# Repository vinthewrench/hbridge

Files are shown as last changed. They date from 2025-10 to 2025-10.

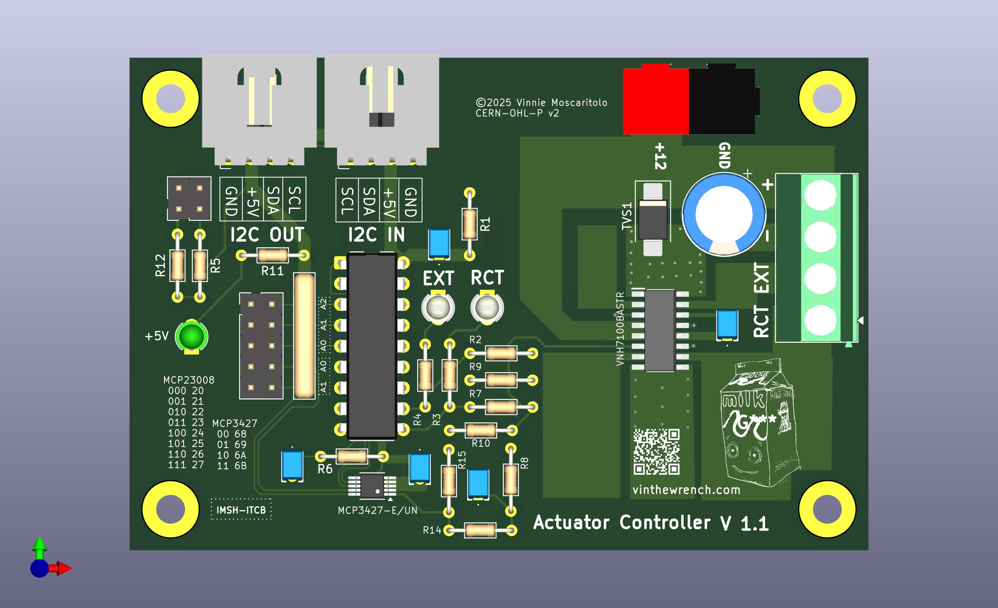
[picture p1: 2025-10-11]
Hbridge F.jpg

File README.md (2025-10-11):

# Actuator Controller – I²C Smart H-Bridge Board

This board is a smart linear actuator controller that uses a VNH7100BAS H-bridge with current sensing and I²C control. It is designed for 12 V actuators, supports stall/jam detection, and is chainable over I²C so you can run multiple actuators from one controller without burning GPIO pins.

This board is part of my distributed control system and is compatible with my nodeLync I²C wiring standard.

## Features
- Drives 12 V linear actuators (extend/retract)
- Solid-state H-bridge (no relays to weld shut)
- Current sensing for stall/jam detection
- I²C control using MCP23008 GPIO expander
- Optional MCP3427 ADC for current telemetry
- Motor power terminal or Anderson Powerpole input
- Status LEDs for power and activity
- Designed for Raspberry Pi or microcontroller systems
- Open hardware – modify it, build it, use it

## I²C Addresses
	| Device        | Base Address | Configurable         |
	|---------------|--------------|----------------------|
	| MCP23008 GPIO | 0x20–0x27    | Yes (A0–A2 jumpers)  |
	| MCP3427 ADC   | 0x68–0x6B    | Yes (ADDR pin)       |

## Current Measurement
The VNH7100BAS provides a current sense output. In 12-bit mode:
Useful for overload protection and detecting mechanical faults.

## Documentation
Full design writeup:
https://www.vinthewrench.com/p/the-humble-actuator

Demo video:
https://youtu.be/HOyxq8rQfaQ

## Status
✅ Prototype tested  
✅ Verified on Raspberry Pi  
✅ Load tested with Progressive Automations PA-10 and PA-14 actuators  
✅ Ready for fabrication / community mods

## License
This is Open Hardware under the CERN-OHL-P v2 license.

You can build it, modify it, use it commercially, and keep modifications private if you want. Just do not remove the original credit.

SPDX-License-Identifier: CERN-OHL-P-2.0  
© 2025 Vinnie Moscaritolo

## Contributions
Issues and pull requests are welcome. If you build one, I would like to see it.

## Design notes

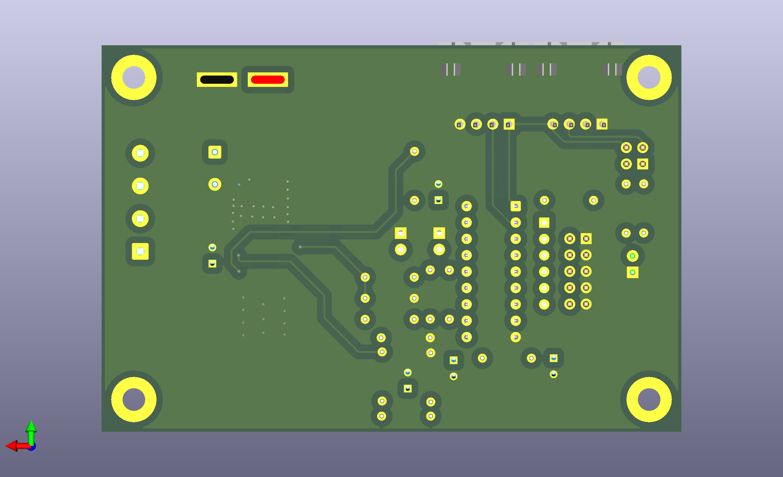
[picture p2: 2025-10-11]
Hbridge B.png

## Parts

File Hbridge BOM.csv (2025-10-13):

H-Bridge Bill of materials
Quantity | Designator | Designation | Mfg Part | Supplier Part | Cost | Ext | Footprint
5 | C21,C5,C6,C2,C1 | .1uf | RCER71H104K0DBH03A | 81-RCER71H104K0DBH3A | $0.18 | $0.92 | Multilayer Ceramic Capacitors MLCC - Leaded .1UF 50V 10% 2.5MM
1 | C3 | 1000uf | EEU-FR1E102 | 667-EEU-FR1E102 | $0.45 | $0.45 | Aluminum Electrolytic Capacitors - Radial Leaded 25VDC 1000uF 10x20mm
2 | J1, J2 | nodeLync socket | 538-70551-0003 | 70551-0003 | $1.19 | $2.38 | Molex Headers & Wire Housings SL 4 CKT W-T-B SHROU
 | J3 | Conn_02x05_Odd_Even |  |  |  | 0
1 | J4 | Screw_Terminal_01x4 | 1715747 | 651-1715747 | $2.21 | $2.21 | Fixed Terminal Blocks 4P 5.08mm 90DEG
1 | J5 | 45A-VERT-PAIR | SSQ-108-04-L-D | 200-SSQ10804LD | $3.28 | $3.28 | Heavy Duty Power Connectors PP PCB STRAIGHT
1 | J6 | Conn_02x02_Odd_Even |  |  |  | 0
3 | LED3,LED2,LED1 | LED 3mm Green/Red | 151033GS03000 | 710-151033GS03000 | $0.25 | $0.75 | Single Color LEDs WL-TMRW THT Mono Waterclr Rnd 3mm Grn
4 | R4,R12,R5,R3 | 4.7K | MBA02040C4701FRP00 | 594-5063JD4K700FT | $0.11 | $0.44 | Metal Film Resistors - Through Hole .4watt 4.7Kohms 1% 1/8watt
1 | R11 | 150 | MBA02040C1500FRP00 | 594-5063JD150R0FT | $0.10 | $0.10 | Metal Film Resistors - Through Hole .4watt 150ohms 1% 1/8watt
6 | R6,R14,R15,R9,R10,R1 | 10K | MBA02040C1002FRP00 | 594-5063JD10K1%TR | $0.10 | $0.60 | Metal Film Resistors - Through Hole .4watt 10Kohms 1% 1/8watt
3 | R7,R8,R2 | 1K | MBA02040C1001FRP00 | 594-5063JD1K000FT | $0.10 | $0.30 | Metal Film Resistors - Through Hole .4watt 1Kohms 1% 1/8watt
1 | RN1 | 10K | 4606M-101-103LF | 652-4606M-1LF-10K | 0.57 | 0.57 | Resistor Networks & Arrays 6pins 10Kohms Bussed
8 | TSV1 | P6SMB18A | P6SMB18A | 652-P6SMB18A | $0.22 | $1.76 | ESD Protection Diodes / TVS Diodes 18V 600W UniDir
1 | U1 | MCP23008-E/P | MCP23008-E/P | 579-MCP23008-E/P | $1.54 | $1.54 | Interface - I/O Expanders In/Out I2C int DIP
1 | U2 | VNH7100BASTR | VNH7100BASTR | 511-VNH7100BASTR | $3.38 | $3.38 | Motor / Motion / Ignition Controllers & Drivers Low Side Driver 1.5A /3A A 595-DRV103H/2K5
1 | U3 | MCP3427-E/UN |  | 579-MCP3427E/UN | $3.68 | $3.68
1 | PCB | PCBoard 60*90 |  |  | $0.65 | $0.65 | PCBway board
 |  |  |  |  | Total Cost | $23.01

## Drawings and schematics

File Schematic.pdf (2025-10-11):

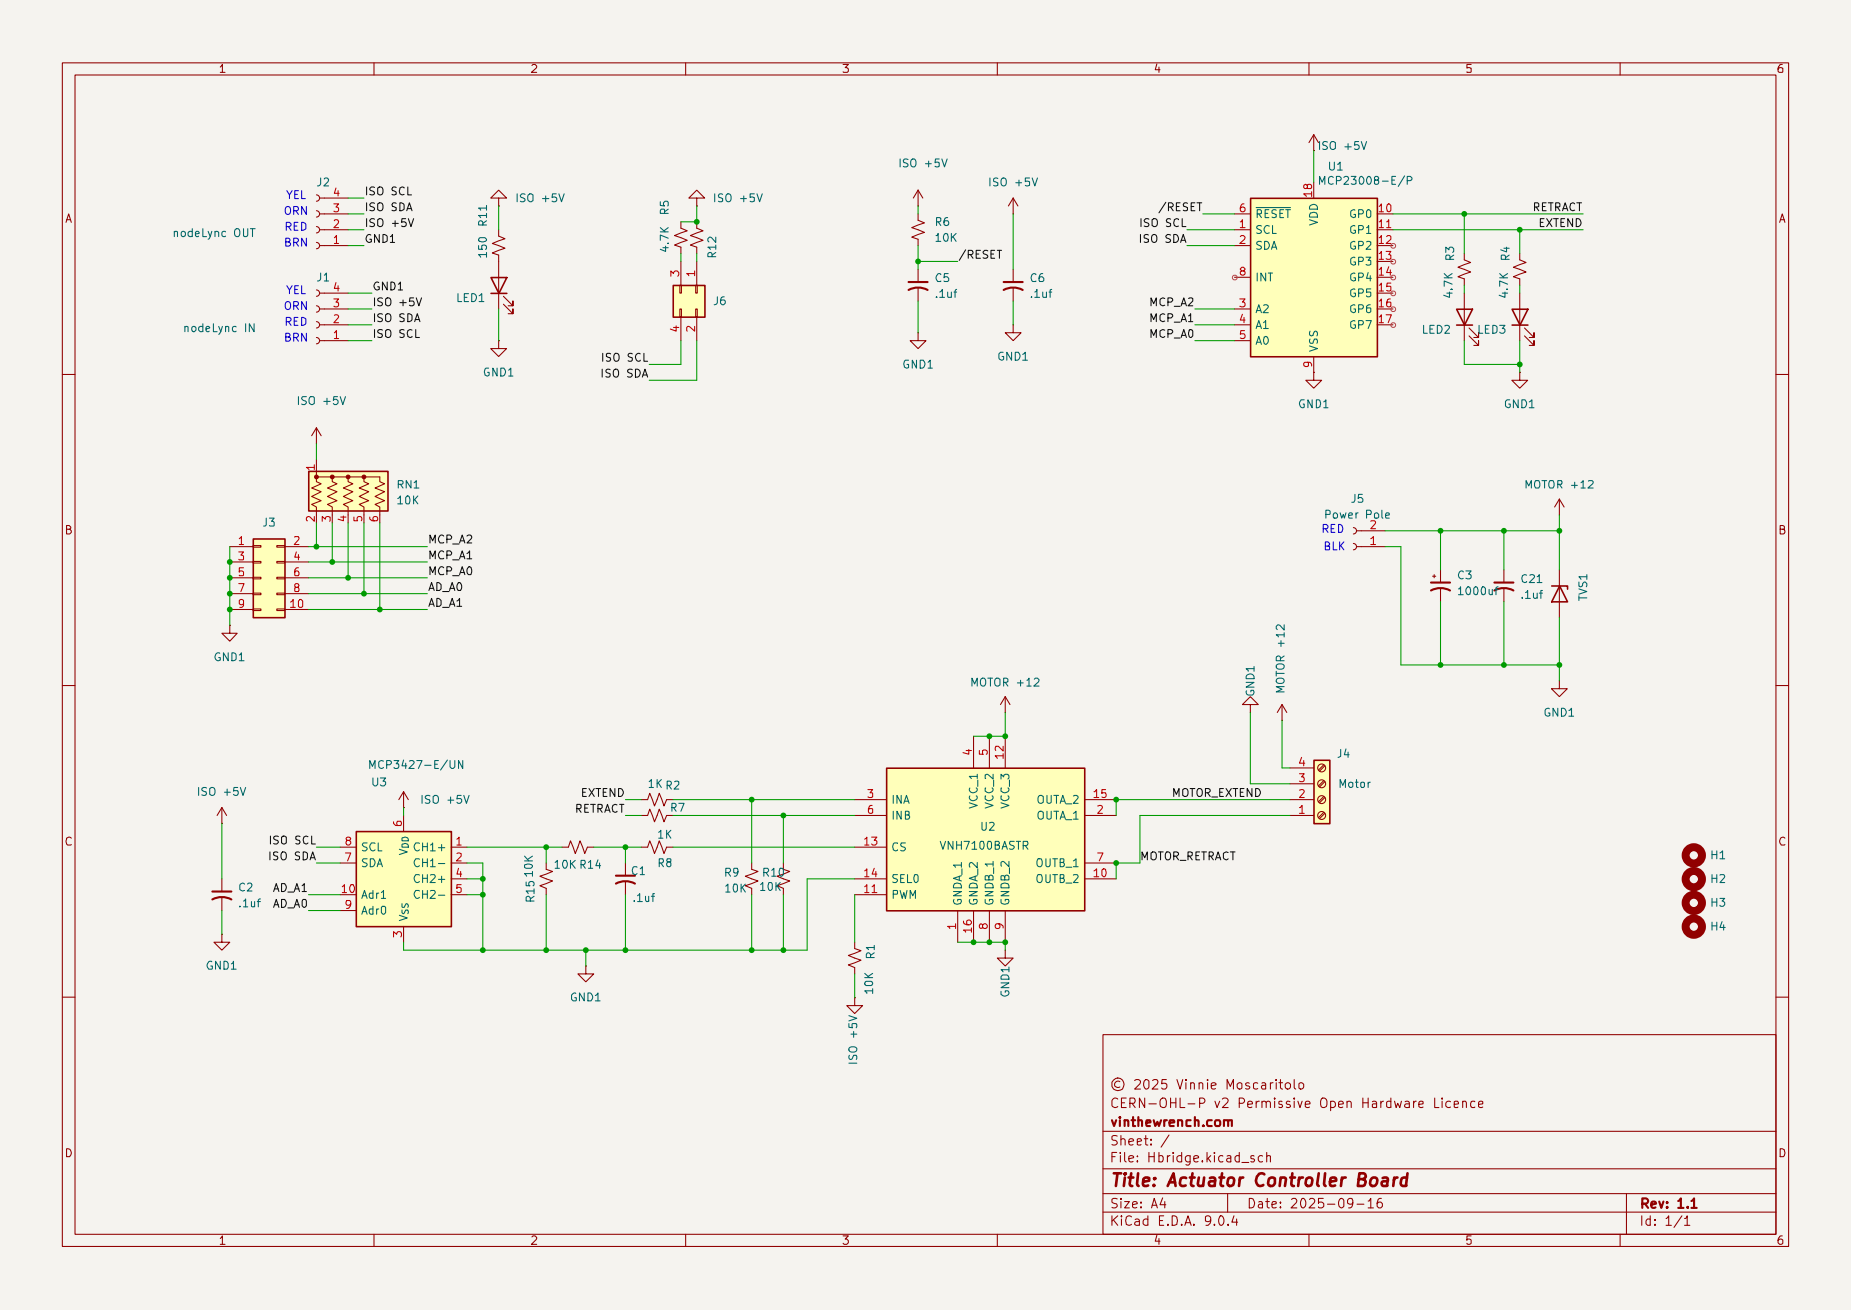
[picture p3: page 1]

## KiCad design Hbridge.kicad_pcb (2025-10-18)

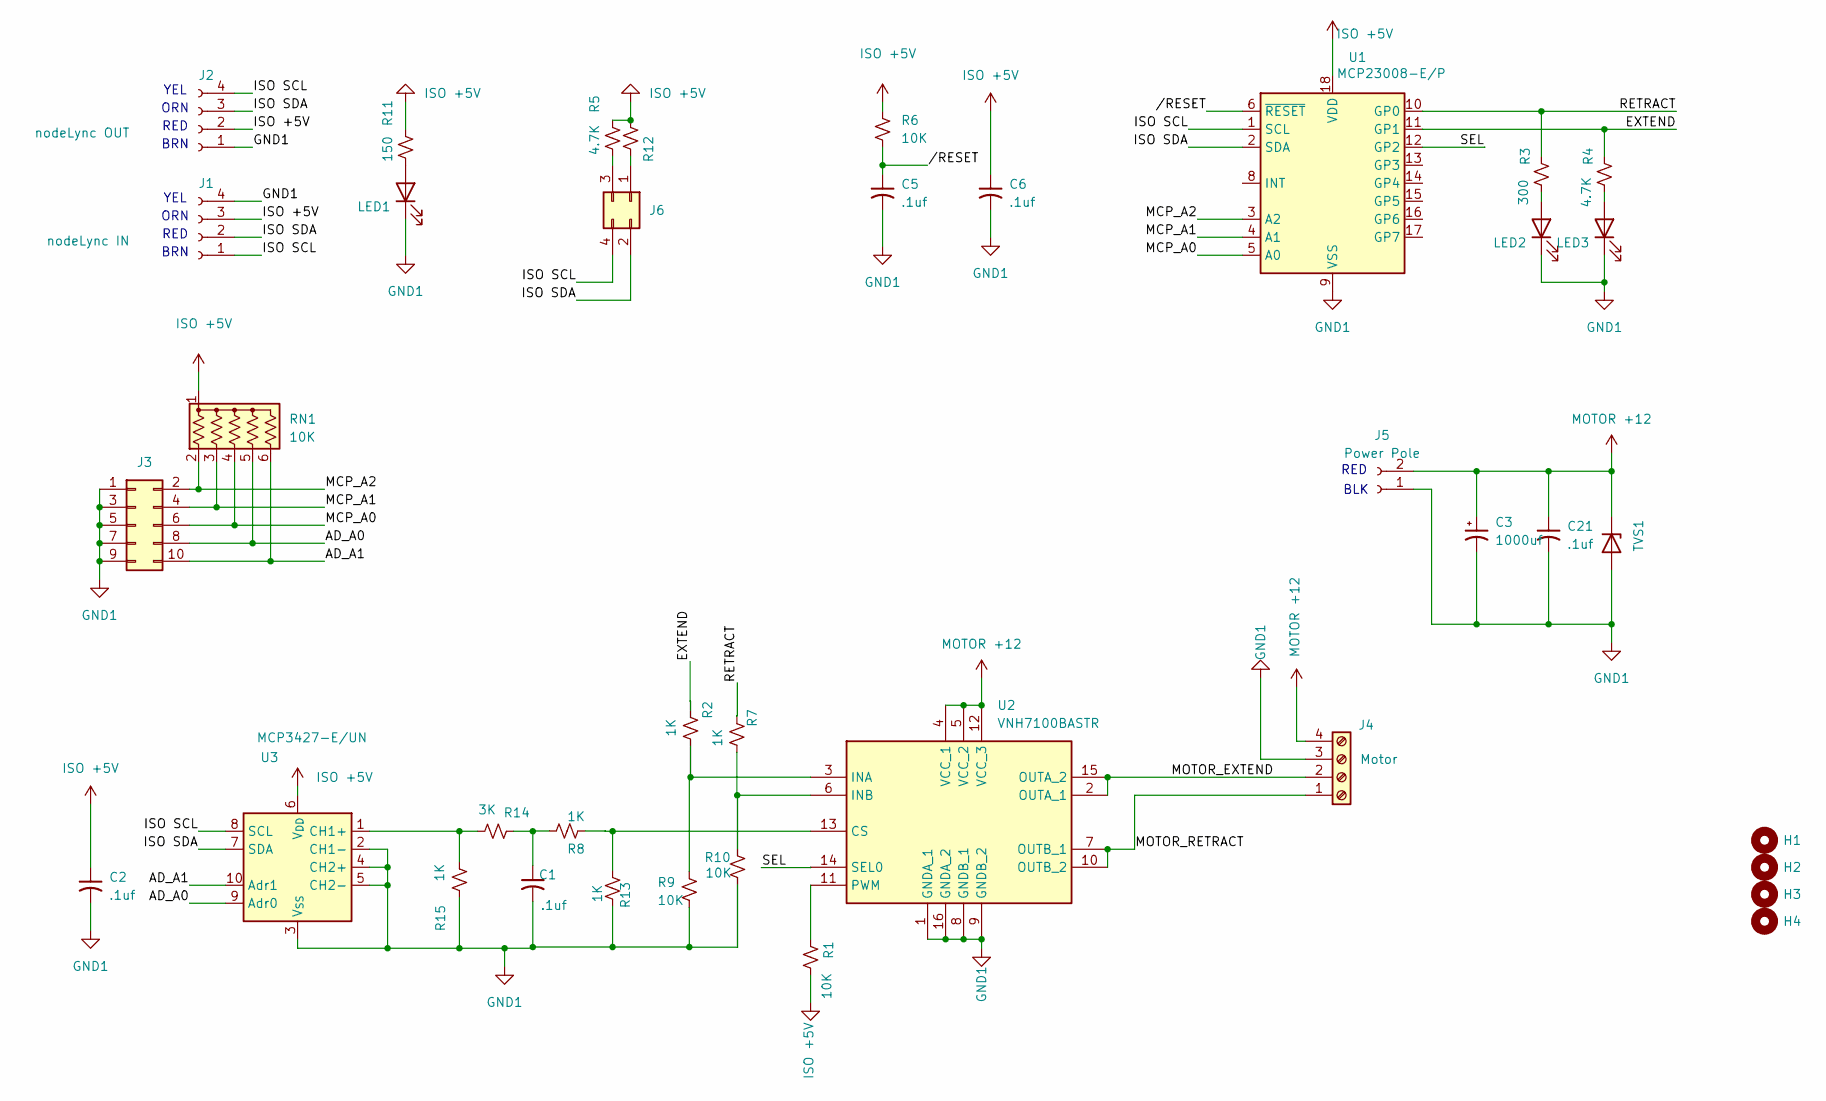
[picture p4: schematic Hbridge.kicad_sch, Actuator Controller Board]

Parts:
C1, C2, C5, C6, C21: .1uf; RCER71H104K0DBH03A
C3: 1000uf; CP_Radial_D10.0mm_P5.00mm
H1, H2, H3, H4: MountingHole
J1: nodeLync IN; PinHeader_1x04_P2.54mm_Horizontal
J2: nodeLync OUT; PinHeader_1x04_P2.54mm_Horizontal
J3: Conn_02x05_Odd_Even; PinHeader_2x05_P2.54mm_Vertical
J4: Motor; TerminalBlock_Phoenix_MKDS-1,5-4-5.08_1x04_P5.08mm_Horizont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
J5: Power Pole; 45A-VERT-PAIR
J6: Conn_02x02_Odd_Even; PinHeader_2x02_P2.54mm_Vertical
LED1, LED2, LED3: 151033GS03000; LED_D3.0mm
R1, R6, R9, R10: 10K; R_Axial_DIN0204_L3.6mm_D1.6mm_P7.62mm_Horizontal
R2, R7, R8, R13, R15: 1K; R_Axial_DIN0204_L3.6mm_D1.6mm_P7.62mm_Horizontal
R3: 300; R_Axial_DIN0204_L3.6mm_D1.6mm_P7.62mm_Horizontal
R4, R5, R12: 4.7K; R_Axial_DIN0204_L3.6mm_D1.6mm_P7.62mm_Horizontal
R11: 150; R_Axial_DIN0204_L3.6mm_D1.6mm_P7.62mm_Horizontal
R14: 3K; R_Axial_DIN0204_L3.6mm_D1.6mm_P7.62mm_Horizontal
RN1: 10K; R_Array_SIP6
TVS1: P6SMB18A; D_SMB_Handsoldering
U1: MCP23008-E/P; DIP-18_W7.62mm
U2: VNH7100BASTR; SOIC127P600X175-16N; Manufacturer_Part_Number VNH7100BASTR; Mouser Part Number 511-VNH7100BASTR
U3: MCP3427-E/UN; MSOP-10_3x3mm_P0.5mm

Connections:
/AD_A0: J3.8, RN1.5 (R4), U3.9 (Adr0)
/AD_A1: J3.10, RN1.6 (R5), U3.10 (Adr1)
/EXTEND: R2.2, R4.2, U1.11 (GP1)
/ISO SCL: J1.1, J2.4, J6.4, U1.1 (SCL), U3.8 (SCL)
/ISO SDA: J1.2, J2.3, J6.2, U1.2 (SDA), U3.7 (SDA)
/MCP_A0: J3.6, RN1.4 (R3), U1.5 (A0)
/MCP_A1: J3.4, RN1.3 (R2), U1.4 (A1)
/MCP_A2: J3.2, RN1.2 (R1), U1.3 (A2)
/MOTOR_EXTEND: J4.2, U2.2 (OUTA_1), U2.15 (OUTA_2)
/MOTOR_RETRACT: J4.1, U2.7 (OUTB_1), U2.10 (OUTB_2)
/RETRACT: R3.2, R7.2, U1.10 (GP0)
/SEL: U1.12 (GP2), U2.14 (SEL0)
//RESET: C5.1, R6.2, U1.6 (~RESET)
GND1: C1.2, C2.2, C3.2, C5.2, C6.2, C21.2, J1.4, J2.1, J3.1, J3.3, J3.5, J3.7, J3.9, J4.3, J5.1, LED1.1 (K), LED2.1 (K), LED3.1 (K), R9.2, R10.2, R13.1, R15.2, TVS1.2 (A), U1.9 (VSS), U2.1 (GNDA_1), U2.8 (GNDB_1), U2.9 (GNDB_2), U2.16 (GNDA_2), U3.2 (CH1-), U3.3 (V_{SS}), U3.4 (CH2+), U3.5 (CH2-)
ISO +5V: C2.1, C6.1, J1.3, J2.2, R1.2, R5.2, R6.1, R11.2, R12.2, RN1.1 (common), U1.18 (VDD), U3.6 (V_{DD})
MOTOR +12: C3.1, C21.1, J4.4, J5.2, TVS1.1 (K), U2.4 (VCC_1), U2.5 (VCC_2), U2.12 (VCC_3)
unnamed: C1.1, R8.1, R14.2
unnamed: J6.1, R12.1
unnamed: J6.3, R5.1
unnamed: LED1.2 (A), R11.1
unnamed: LED2.2 (A), R3.1
unnamed: LED3.2 (A), R4.1
unnamed: R8.2, R13.2, U2.13 (CS)
unnamed: R2.1, R9.1, U2.3 (INA)
unnamed: R7.1, R10.1, U2.6 (INB)
unnamed: R1.1, U2.11 (PWM)
unnamed: R14.1, R15.1, U3.1 (CH1+)

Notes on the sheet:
ORN
YEL
BRN
RED
BLK
RED

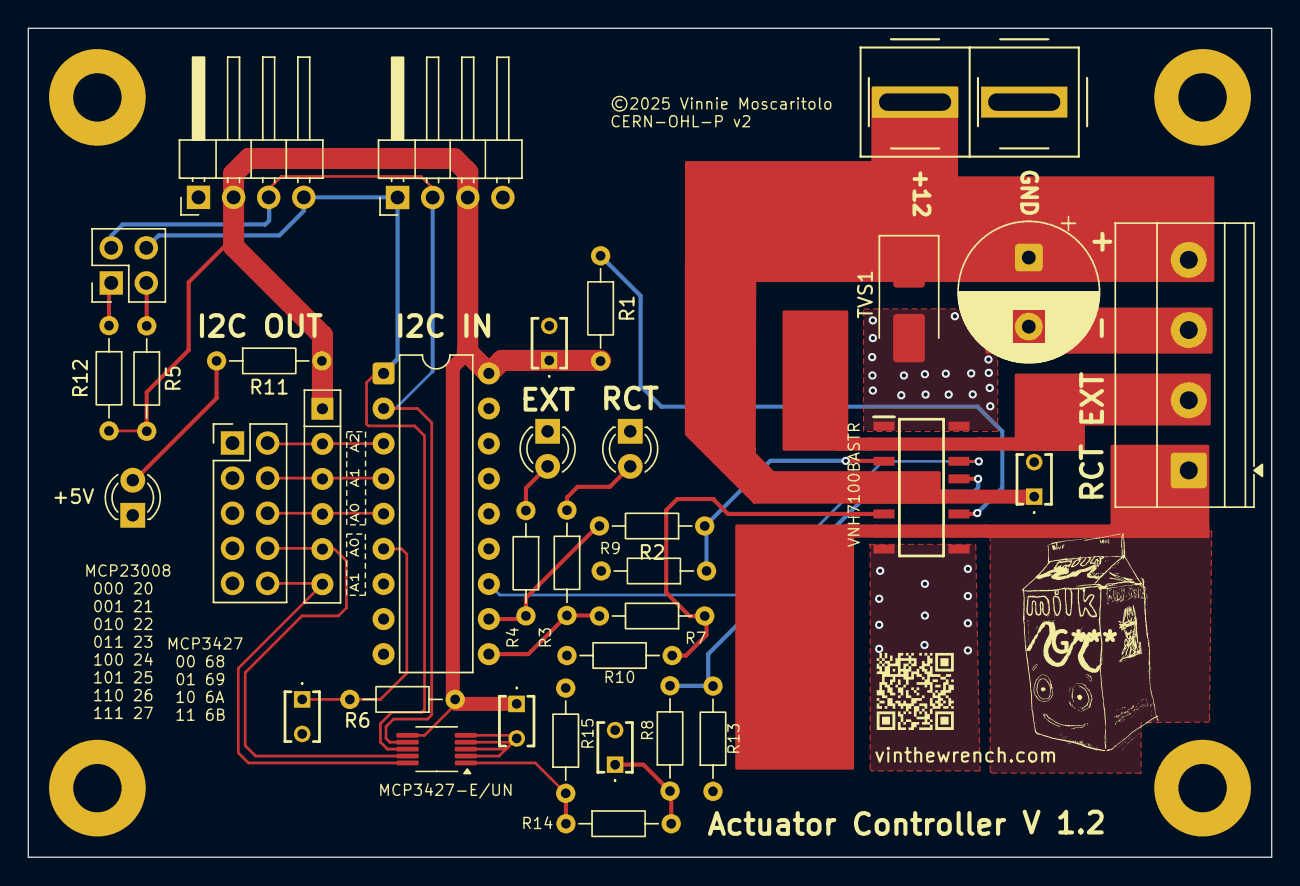
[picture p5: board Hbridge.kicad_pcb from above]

Board: 2 copper layers, 90.0 x 60.0 mm, 39 parts (0 on the bottom side), 27 nets.

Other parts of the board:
H1#2, H1#3, H1#4: MountingHole_3.5mm_Pad

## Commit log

2025-10-13 update BOM
    [Hbridge BOM.csv]
2025-10-18 corrected issues with sense resistor for CS and SEL
    [Hbridge.kicad_pcb, Hbridge.kicad_sch]

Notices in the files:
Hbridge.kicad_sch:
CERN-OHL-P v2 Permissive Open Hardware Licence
